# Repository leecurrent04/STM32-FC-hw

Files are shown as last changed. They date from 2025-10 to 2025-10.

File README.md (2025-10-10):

# NARAEON (나래온)

**NARAEON**은 인하대학교 모형항공기 동아리 '나래'(NARAE)에서 개발 중인 오픈소스 비행제어컴퓨터(FC) 프로젝트입니다. 이 프로젝트는 학술적 연구, 개발 그리고 취미 활동을 목적으로 하는 모든 분들을 위해 하드웨어, 펌웨어를 포함하고 있습니다.

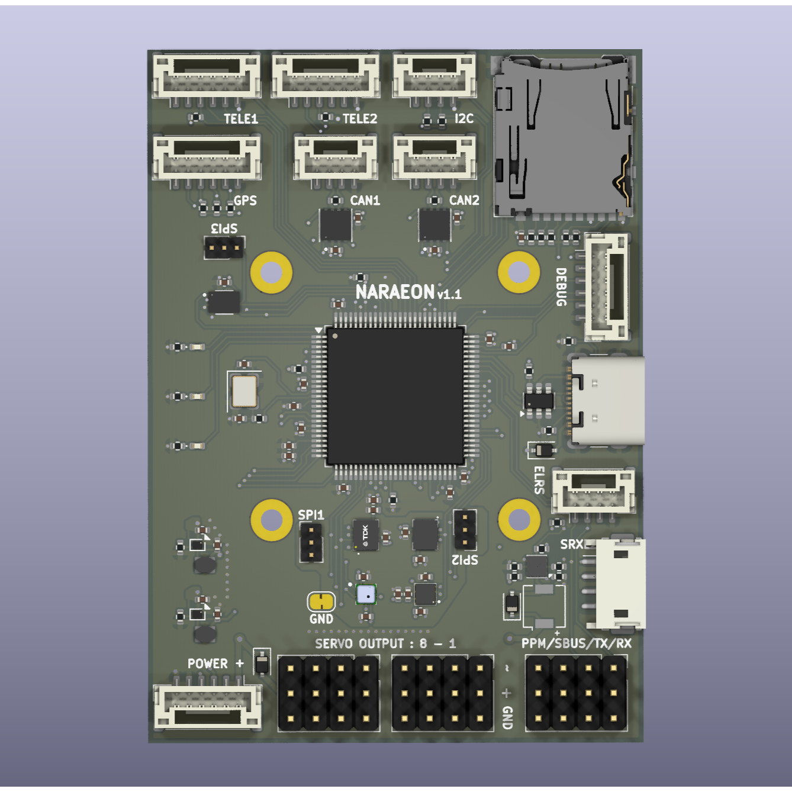
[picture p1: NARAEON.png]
pcb img


## 🌟 프로젝트 소개
NARAEON은 무인항공기(UAV)의 핵심인 **비행제어컴퓨터**와 주요 센서들을 아우르는 통합 플랫폼입니다. 
저희는 항공전자 분야를 처음 배우는 학생들이 쉽게 학습하고 새로운 기능을 구현 및 창조할 수 있는 플랫폼을 제공하고자 이 프로젝트를 시작하게 되었습니다.

## ✨ 주요 특징
- 오픈소스: 하드웨어 회로도부터 펌웨어 소스 코드까지 모든 것이 공개되어 있어 누구나 자유롭게 사용하고, 수정하며, 기여할 수 있습니다.
- 통합 플랫폼: 비행 제어에 필요한 컴퓨터와 핵심 센서를 포함하여 안정적인 비행 제어 솔루션을 제공합니다.
- 확장성: 다양한 종류의 무인항공기에 적용할 수 있도록 설계되었으며, 사용자의 필요에 따라 기능을 쉽게 확장할 수 있습니다.
- 교육 및 연구: 학생, 연구자, 개발자들이 비행 제어 시스템의 원리를 깊이 있게 학습하고, 새로운 기술을 실험할 수 있는 훌륭한 교육 및 연구 도구입니다.

## 🚀 시작하기
프로젝트를 시작하는 데 필요한 정보는 각 저장소의 Wiki 페이지나 문서를 참고해 주세요. (링크 추가 예정)

하드웨어: [하드웨어 관련 저장소 링크]

- [STM32-FC](https://github.com/NARAE-INHA-UNIV/STM32-FC) : Firmware & Source code
- [NALDA](https://github.com/NARAE-INHA-UNIV/NALDA) : GCS

## 🔍 HW Spec.

> PCB 보드에 릴리즈 날짜와 버전이 기록되어 있지 않으면 v1.0.0 버전 입니다.
현재 최신 버전은 v1.1.0 입니다.

- ICM-45686 & ICM-42688-P dual IMU
- LIS2MDL eCompass
- ICP-20100 pressure sensor
- 내장 Flash memory & Micro SD card
- IBUS, SBUS, SRXL2, ELRS, PPM RC 프로토콜 지원

## 🤝 기여하기

NARAEON 프로젝트는 여러분의 참여를 언제나 환영합니다! 버그 리포트, 기능 제안, 코드 기여 등 어떤 형태의 기여도 프로젝트 발전에 큰 힘이 됩니다. 기여하고 싶으시다면 다음을 참고해 주세요.

1. 이 저장소를 Fork 하세요.
2. 새로운 기능이나 수정을 위한 Branch를 생성하세요 (git checkout -b feature/AmazingFeature).
3. 코드를 수정하고 Commit 하세요 (git commit -m 'Add some AmazingFeature').
4. Branch에 Push 하세요 (git push origin feature/AmazingFeature).
5. Pull Request를 열어주세요.

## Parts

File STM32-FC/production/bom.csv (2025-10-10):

Designator | Footprint | Quantity | Value | LCSC Part #
BZ1 | FUET-4020 | 1 | FUET-4020 | C391027
C1, C4 | 0402 | 2 | 10pF | C1545
C10, C11, C13, C18, C19, C22, C24, C25, C27, C28, C3, C30, C31, C32, C33, C34, C5, C6, C9 | 0402 | 19 | 100nF | C1525
C12 | 0402 | 1 | 1uF | C14445
C14, C15 | 0402 | 2 | 4.7uF | C307423
C16, C17, C2, C26 | 0402 | 4 | 10uF | C307415
C20 | 0402 | 1 | 10nF | C15195
C21 | 0402 | 1 | 100pF | C152819
C23 | 0402 | 1 | 2.2nF | C84703
C29 | 0402 | 1 | 220nF | C16651
C7, C8 | 0402 | 2 | 2.2uF | C170151
D1 | 0402 | 1 | Red | C130719
D2, D5, D6 | D_SOD-323 | 3 | B5819W | C22624
D3 | 0402 | 1 | Yellow | C130721
D4 | 0402 | 1 | Blue | C130724
J1, J10, J11, J15, J3 | JST_GH_BM06B-GHS-TBT_1x06-1MP_P1.25mm_Vertical | 5 | GH 1.25mm 6P | C189892
J12, J13, J14, J9 | JST_GH_BM04B-GHS-TBT_1x04-1MP_P1.25mm_Vertical | 4 | GH 1.25mm 4P | C161692
J2 | USB_C_Receptacle_GCT_USB4105-xx-A_16P_TopMnt_Horizontal | 1 | USB_C_USB2.0_16P | C2765186
J4 | microSD_HC_Hirose_DM3AT-SF-PEJM5 | 1 | DM3AT-SF-PEJM5 | C114218
J5, J6, J7 | PWM_Conn_3x04_JLC | 3 | PWM_Conn_3x04 | C3325573
J8 | JST_ZH_B4B-ZR-SM4-TF_1x04-1MP_P1.50mm_Vertical | 1 | ZH 1.5mm 4P | C485354
L1, L2 | VLS201610ET-2R2M | 2 | 2.2u | C114768
Q1 | Nexperia_SOT1118 | 1 | PMDPB30XN | C478009
R1, R3 | 0402 | 2 | 100k | C25741
R10 | 0402 | 1 | 1k5 | C25867
R11, R12 | 0402 | 2 | 267k | C2998050
R13, R14, R15, R16, R17, R18, R19, R21, R22, R23, R24, R25, R28, R29, R30, R31, R34 | 0402 | 17 | 10k | C25531
R2 | 0402 | 1 | 4k7 | C25900
R26, R27, R33, R4 | 0402 | 4 | 120 | C25079
R5, R6, R7 | 0402 | 3 | 1k | C11702
R8, R9 | 0402 | 2 | 5k1 | C25905
TP1, TP2, TP3 | PinHeader_1x03_P1.27mm_Vertical | 3 | Test Pin | C24980
U1 | LQFP-100_14x14mm_P0.5mm | 1 | STM32F407VETx | C28730
U10, U11 | VDFN8_3X3_MCH-L | 2 | ATA6561-GBQW | C617297
U2 | SOT-23-6 | 1 | USBLC6-2SC6 | C7519
U3, U4 | Texas_DSBGA-6_0.855x1.255mm_Layout2x3_P0.4mm_LevelC | 2 | TPS62840YBG | C2071139
U5 | USON_LUXIG TR_WIN | 1 | W25X40CLUXIG | C401661
U6 | IIM42352_L | 1 | ICM-42688-P | C1850418
U7 | ICM-45686 | 1 | ICM-45686 | C22459454
U8 | ICP-20100 | 1 | ICP-20100 | C5343527
U9 | LIS2MDLTR | 1 | LIS2MDLRT | C919695
Y1 | Crystal_SMD_Abracon_ABM8G-4Pin_3.2x2.5mm | 1 | 16MHz | C1985423

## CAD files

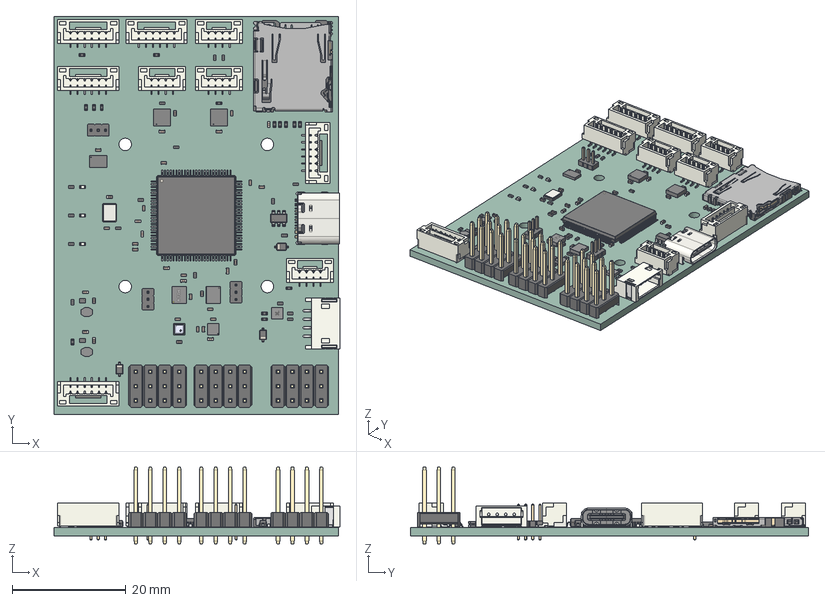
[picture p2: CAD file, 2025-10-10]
NARAEON.step
50.2 x 70.0 x 13.5 mm
LED_0402_1005Metric x 3
LIS2MDLTR
kicad_embedded_6C539A5BD06C60DE5F29B901A99F0E48
R_0402_1005Metric x 32
C_0402_1005Metric x 34
JST_GH_BM04B-GHS-TBT_1x04-1MP_P1.25mm_Vertical x 4
JST_GH_BM06B-GHS-TBT_1x06-1MP_P1.25mm_Vertical x 5
PinHeader_1x03_P1.27mm_Vertical x 3
kicad_embedded_F2643CE658DD47BC4DB3F655A425A60D
3x4 Male Pin Header x 3
Crystal_SMD_Abracon_ABM8G-4Pin_3.2x2.5mm
ICP-20100
SOT1118 LF
SOT1118 Mold Body
S4B-ZR-SM4A-TF
VDFN8_3X3_MCH x 2
D_SOD-323 x 3
USON_LUXIG_TR_WIN
SOT-23-6
USB_C_Receptacle_GCT_USB4105-xx-A_16P_TopMnt_Horizontal
ICM-42688-P
Texas_DSBGA-6_0.757x1.01mm_Layout2x3_P0.35mm x 2
LQFP-100_14x14mm_P0.5mm
kicad_embedded_0F5F1D1E837527C3A2AA1D8B906FDBF7 x 2
microSD_HC_Hirose_DM3AT-SF-PEJM5
STM32-FC_PCB

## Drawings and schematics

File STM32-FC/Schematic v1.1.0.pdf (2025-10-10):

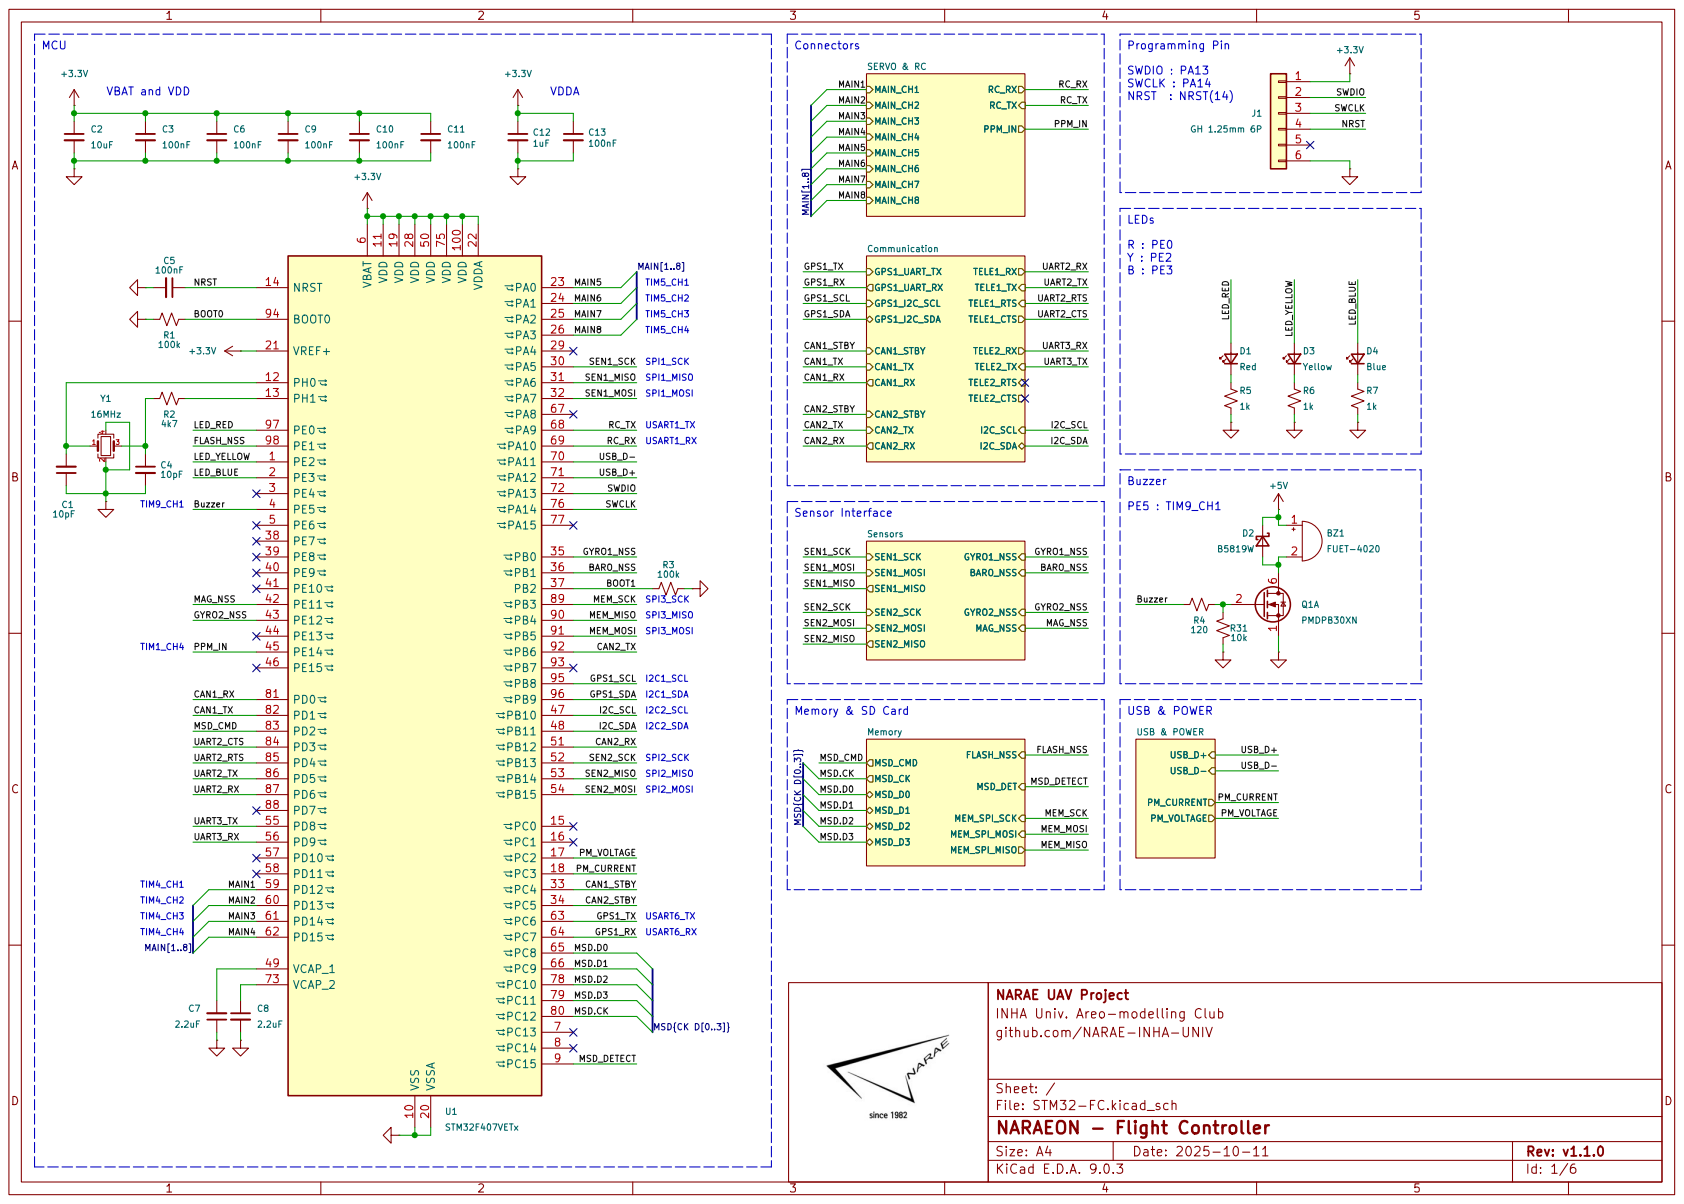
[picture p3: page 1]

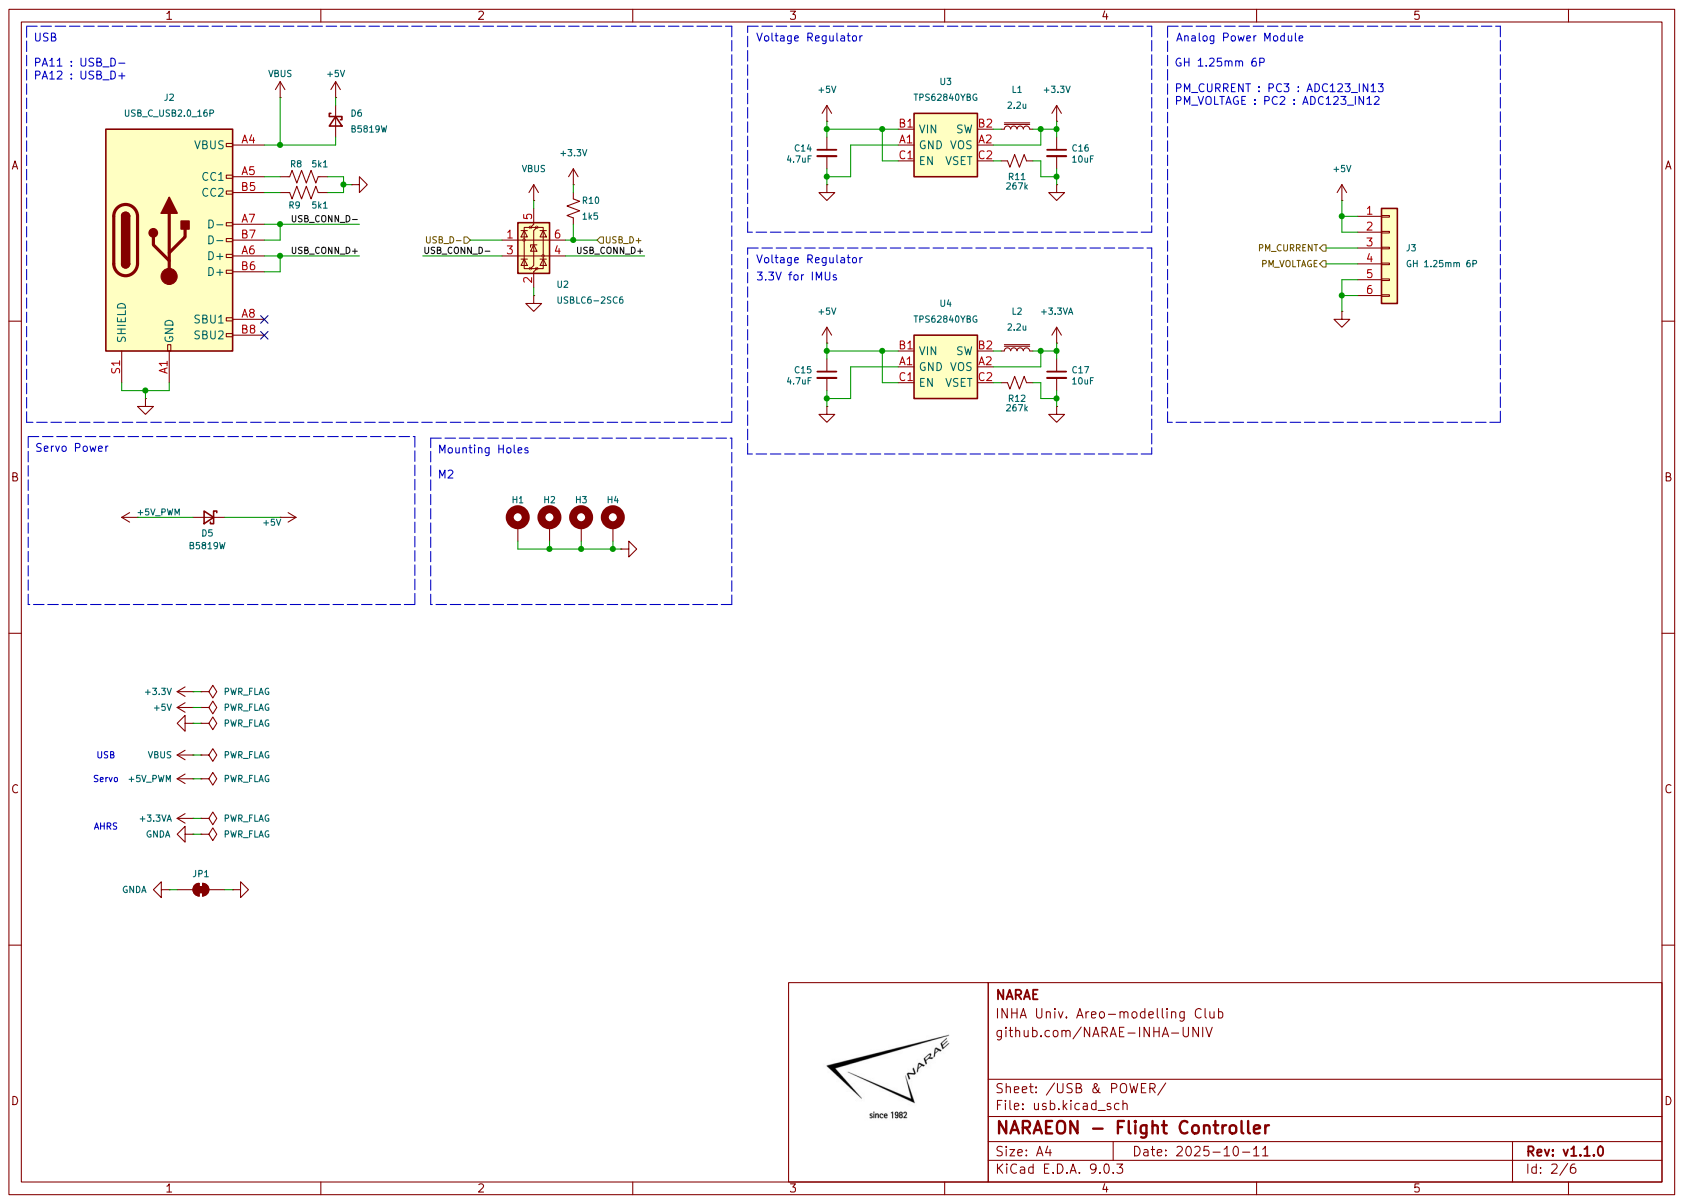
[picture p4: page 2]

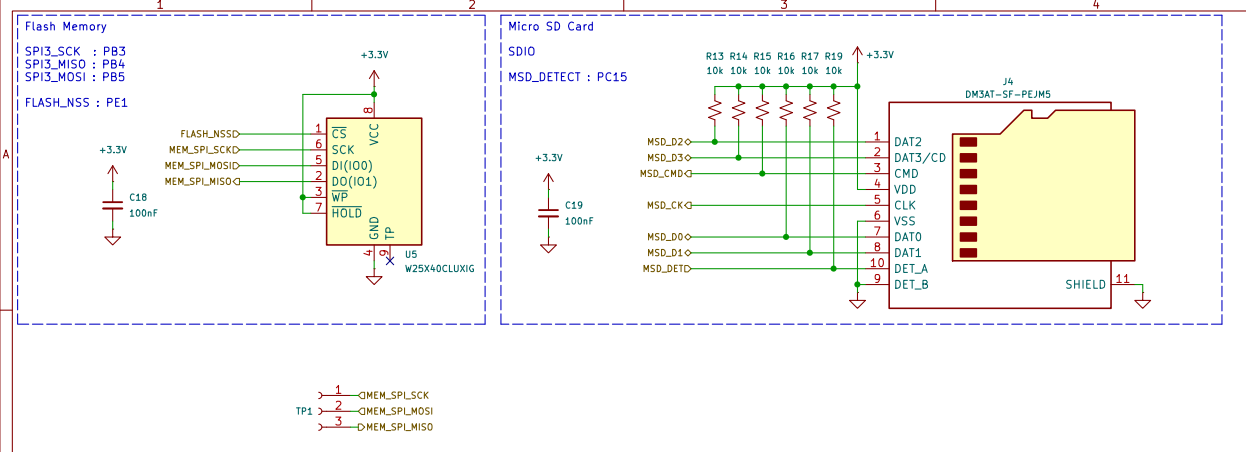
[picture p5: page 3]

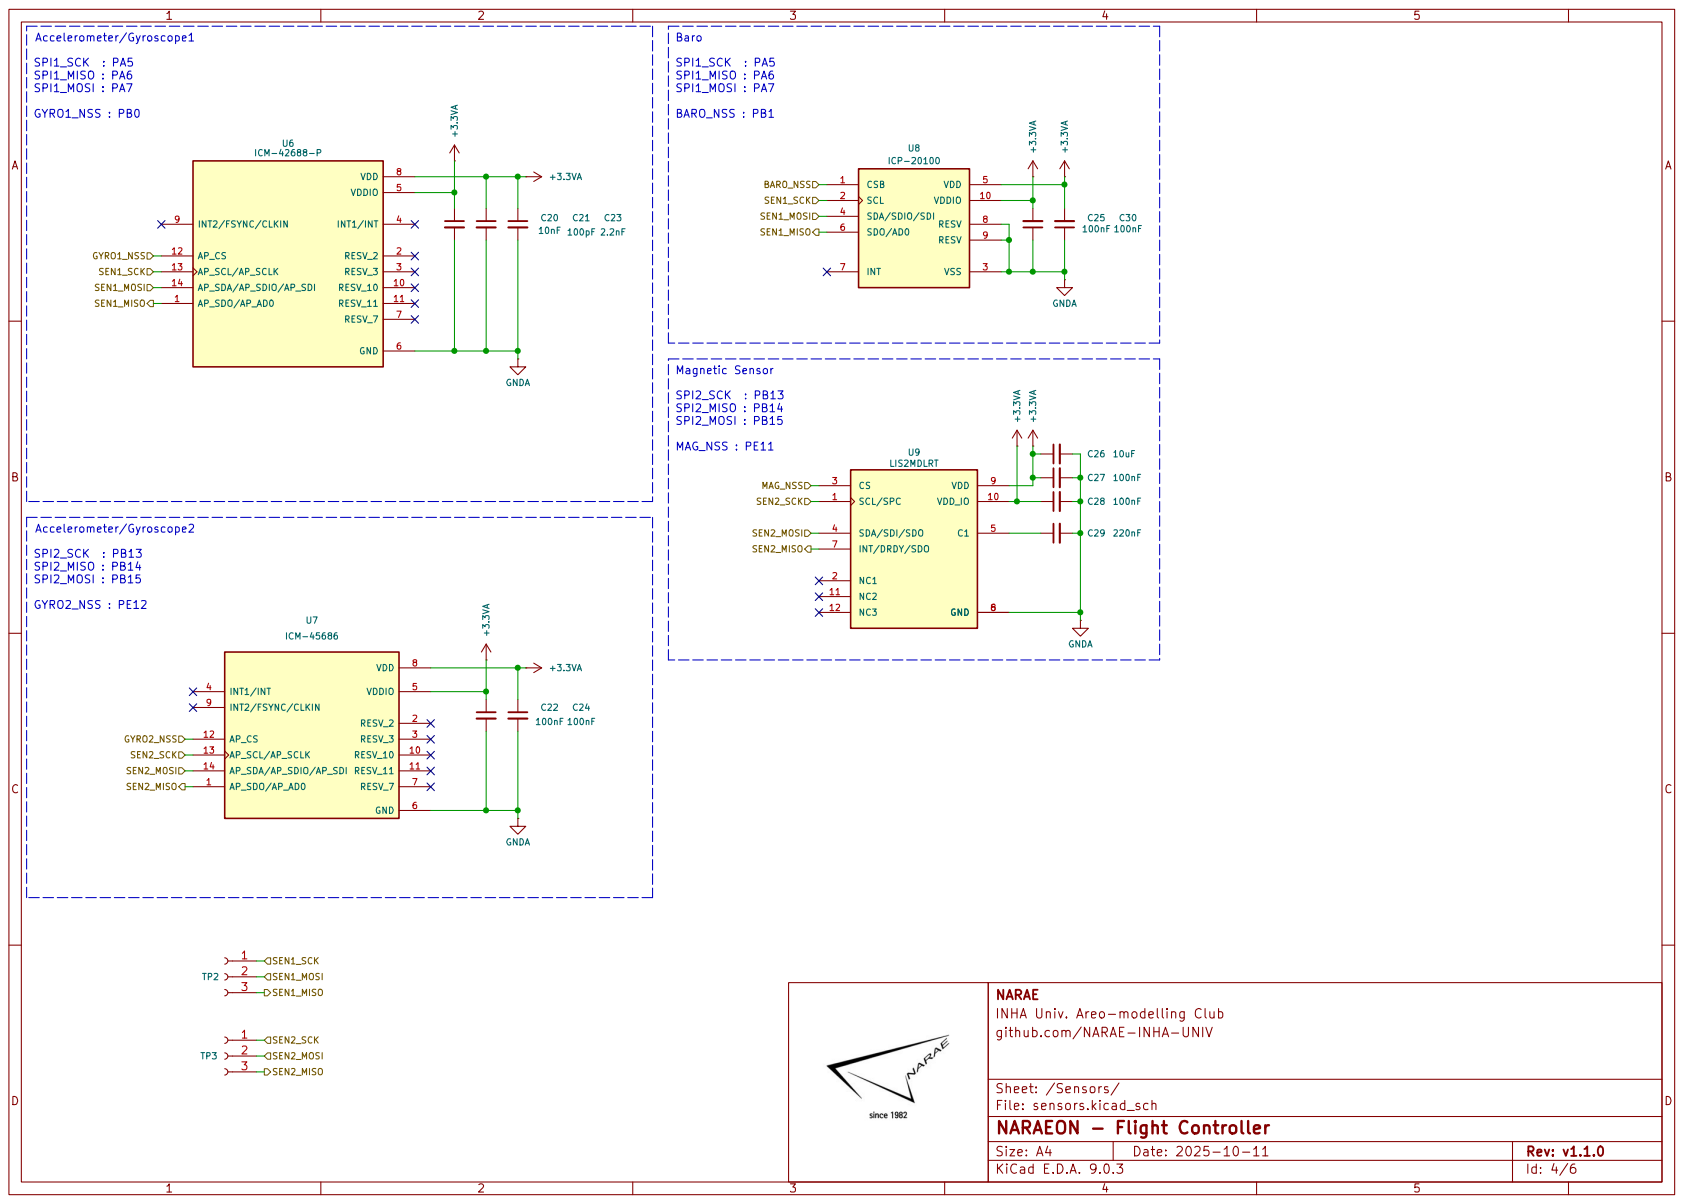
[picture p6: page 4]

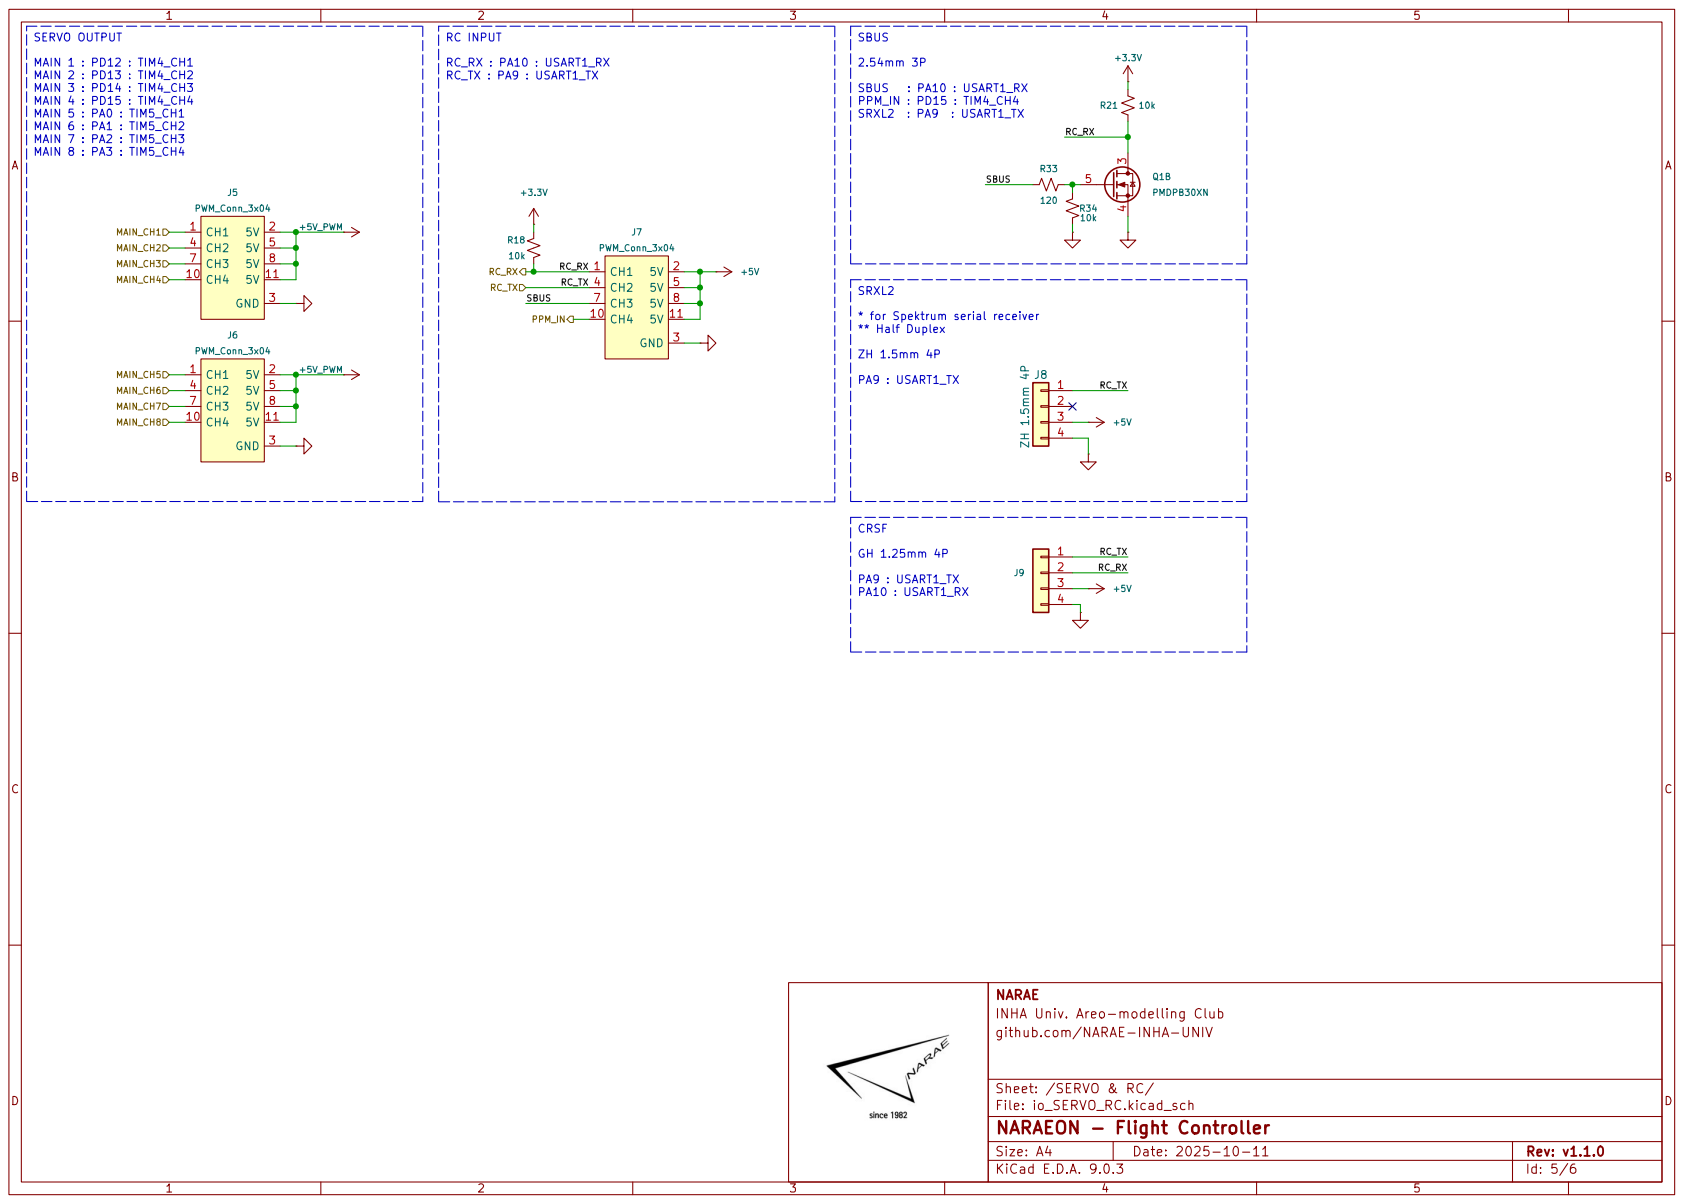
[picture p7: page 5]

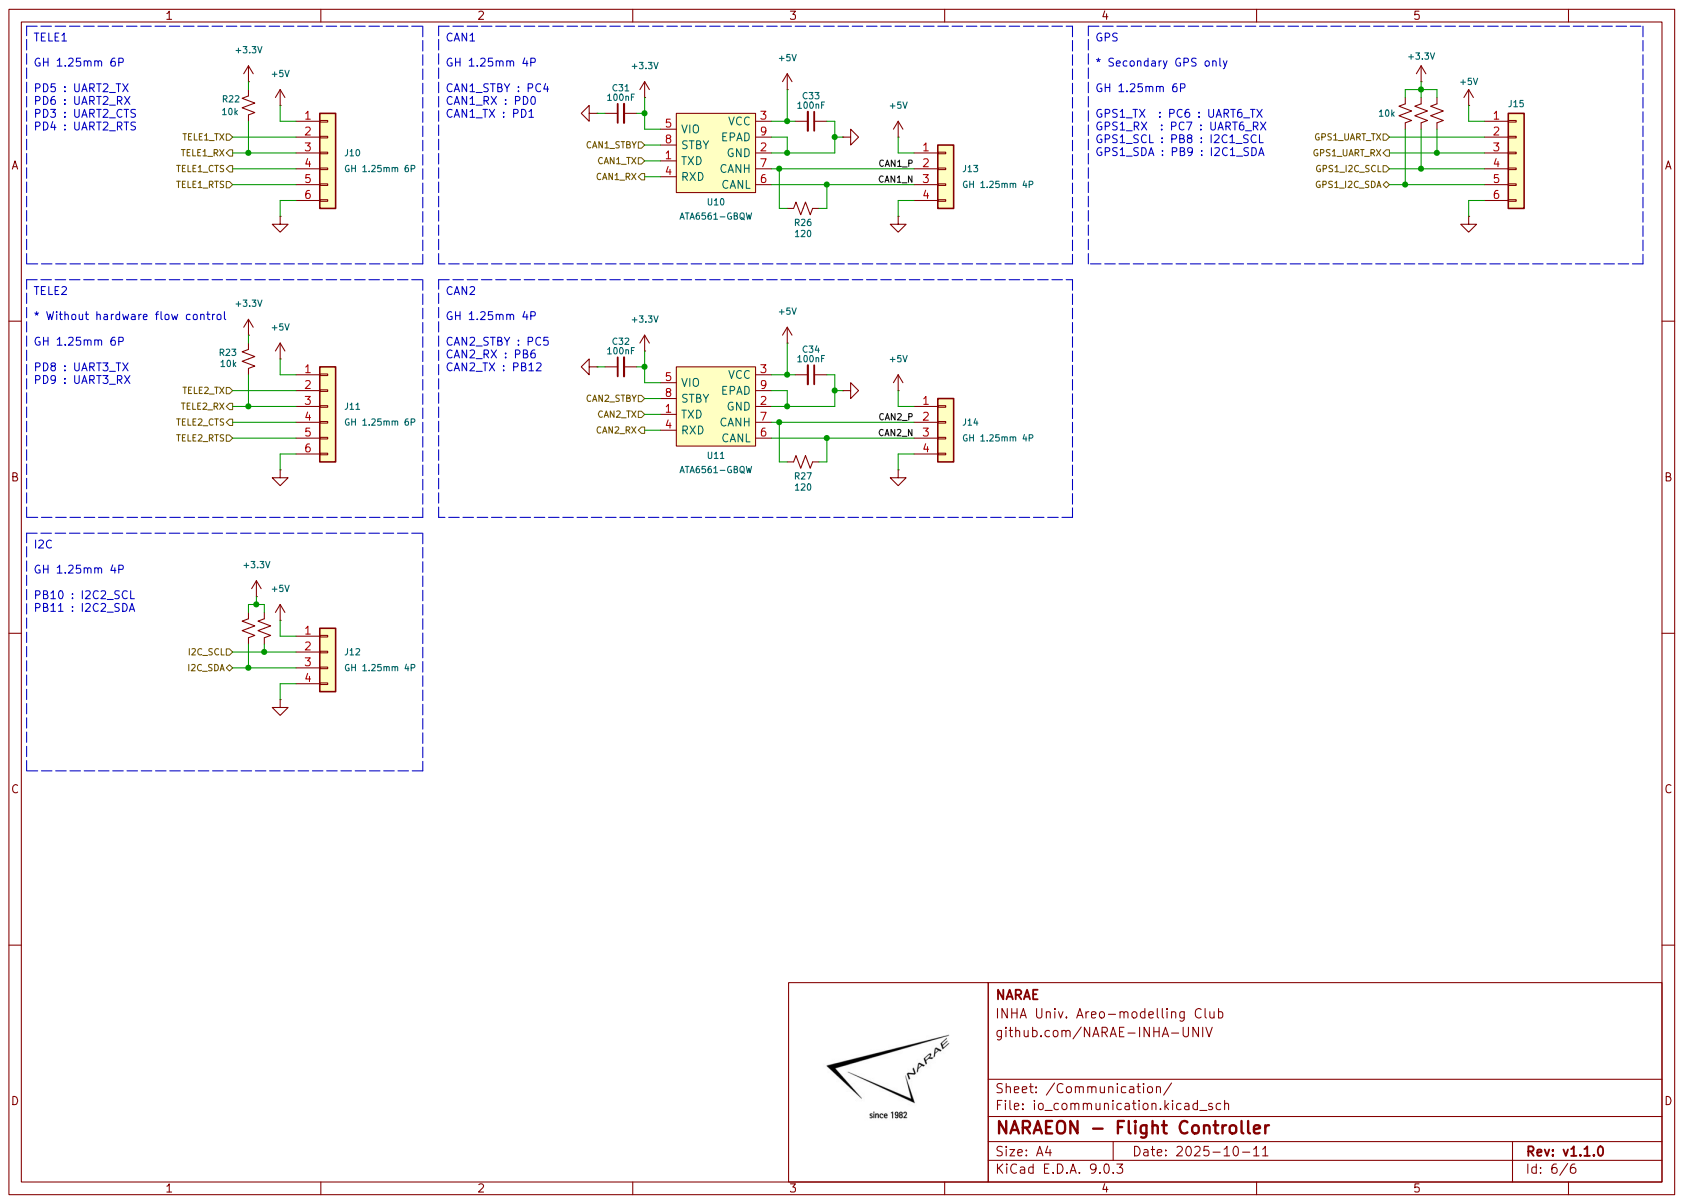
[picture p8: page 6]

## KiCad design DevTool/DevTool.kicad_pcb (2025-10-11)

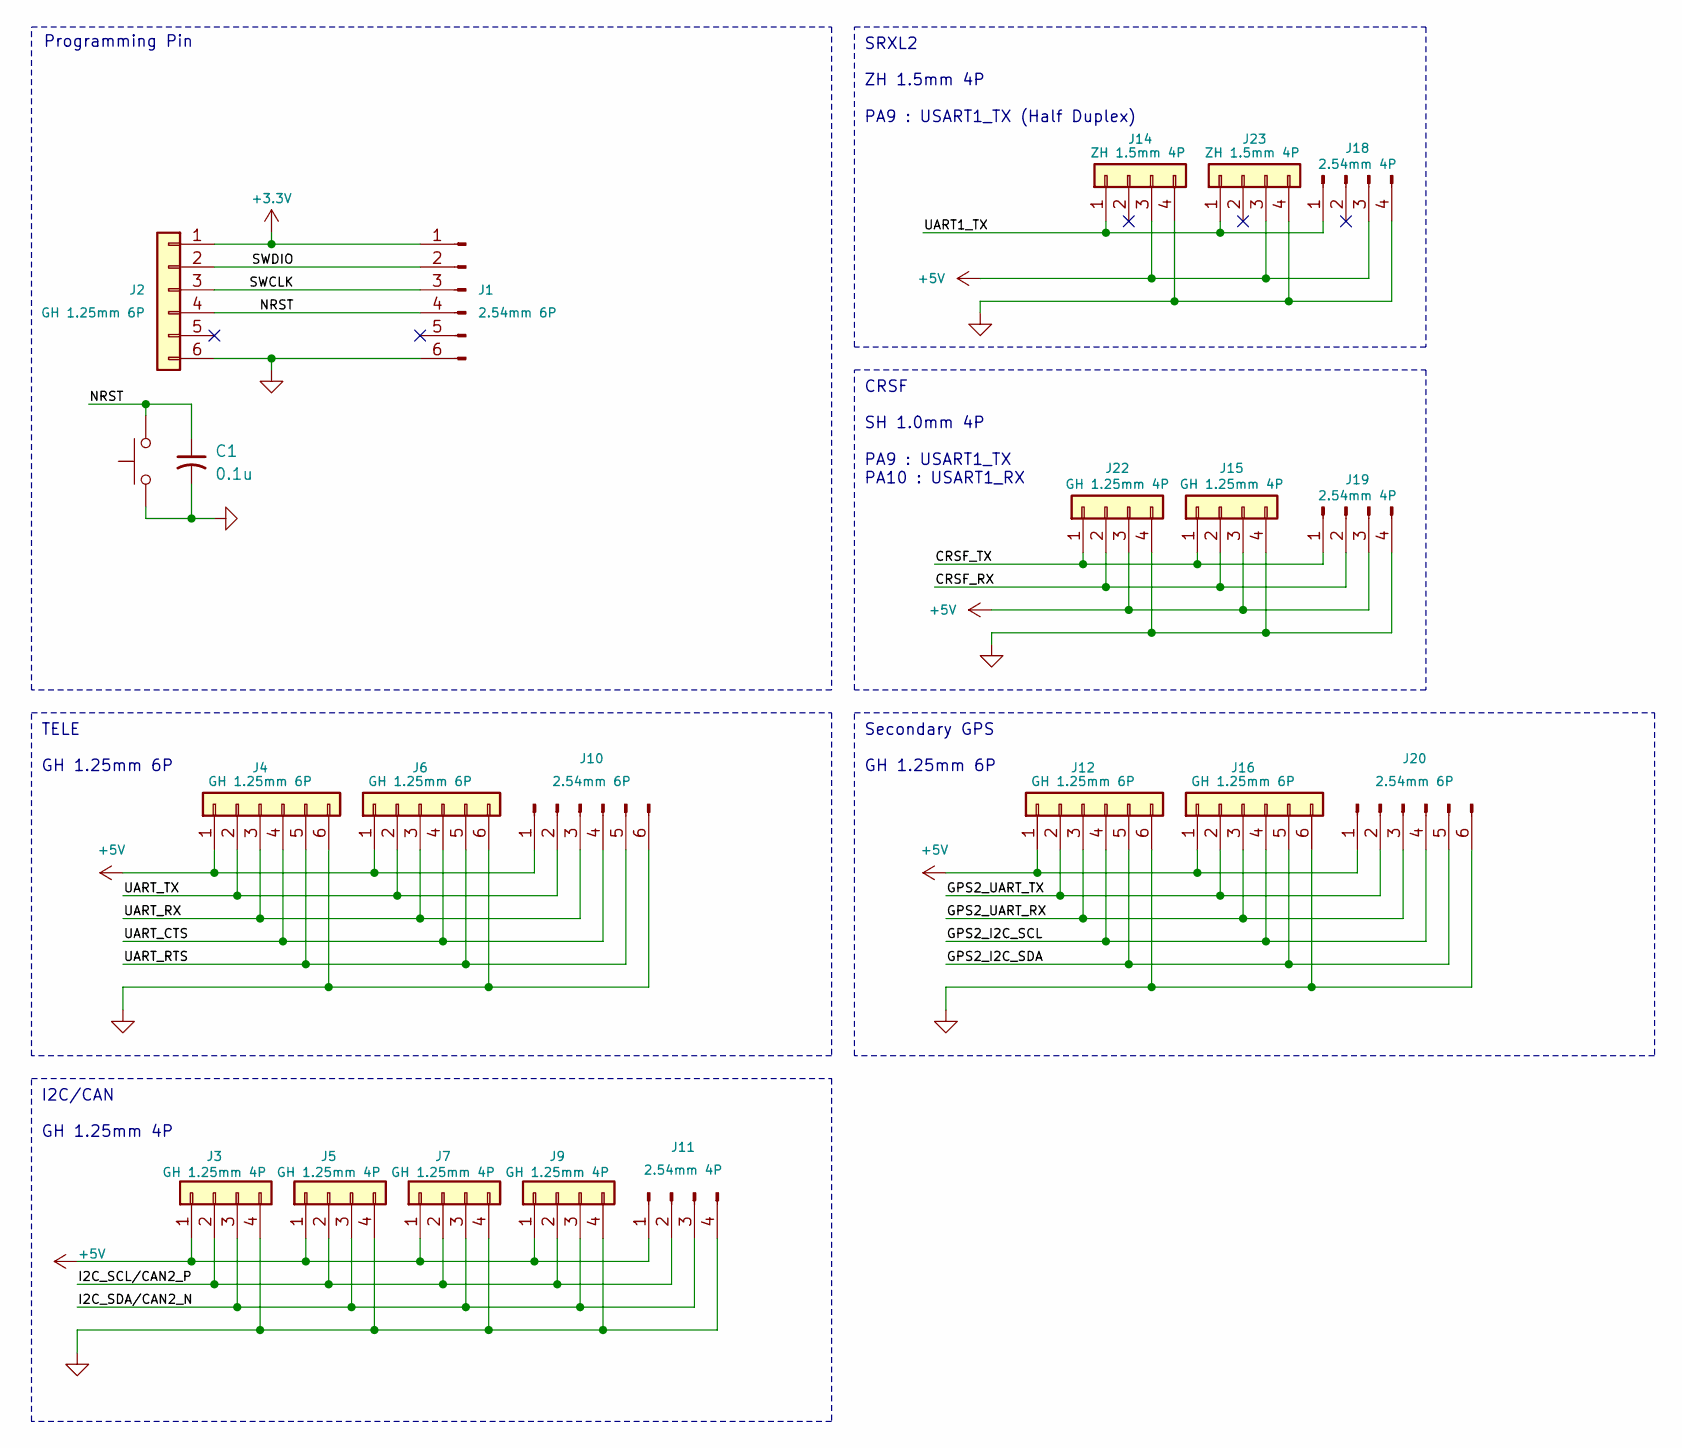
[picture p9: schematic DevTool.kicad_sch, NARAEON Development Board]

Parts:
C1: 0.1u; C_0603_1608Metric
J1, J10, J20: 2.54mm 6P; PinHeader_1x06_P2.54mm_Vertical
J2, J4, J6, J12, J16: GH 1.25mm 6P; JST_GH_BM06B-GHS-TBT_06; LCSC C133065
J3, J5, J7, J9, J15, J22: GH 1.25mm 4P; JST_GH_BM04B-GHS-TBT_04; LCSC C189895
J11, J18, J19: 2.54mm 4P; PinHeader_1x04_P2.54mm_Vertical
J14, J23: ZH 1.5mm 4P; JST_ZH_S4B-ZR-SM4A-TF_1x04-1MP_P1.50mm_Horizontal; LCSC C485354
SW1: SW_Push; SW_SPST_PTS645

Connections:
+3.3V: J1.1, J2.1
+5V: J3.1, J4.1, J5.1, J6.1, J7.1, J9.1, J10.1, J11.1, J12.1, J14.3, J15.3, J16.1, J18.3, J19.3, J20.1, J22.3, J23.3
/CRSF_RX: J15.2, J19.2, J22.2
/CRSF_TX: J15.1, J19.1, J22.1
/GPS2_I2C_SCL: J12.4, J16.4, J20.4
/GPS2_I2C_SDA: J12.5, J16.5, J20.5
/GPS2_UART_RX: J12.3, J16.3, J20.3
/GPS2_UART_TX: J12.2, J16.2, J20.2
/I2C_SCL/CAN2_P: J3.2, J5.2, J7.2, J9.2, J11.2
/I2C_SDA/CAN2_N: J3.3, J5.3, J7.3, J9.3, J11.3
/NRST: C1.1, J1.4, J2.4, SW1.2
/SWCLK: J1.3, J2.3
/SWDIO: J1.2, J2.2
/UART1_TX: J14.1, J18.1, J23.1
/UART_CTS: J4.4, J6.4, J10.4
/UART_RTS: J4.5, J6.5, J10.5
/UART_RX: J4.3, J6.3, J10.3
/UART_TX: J4.2, J6.2, J10.2
GND: C1.2, J1.6, J2.6, J3.4, J4.6, J5.4, J6.6, J7.4, J9.4, J10.6, J11.4, J12.6, J14.4, J15.4, J16.6, J18.4, J19.4, J20.6, J22.4, J23.4, SW1.1

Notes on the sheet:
SRXL2
CRSF
SH 1.0mm 4P PA9 : USART1_TX PA10 : USART1_RX
GH 1.25mm 6P
Programming Pin
TELE
GH 1.25mm 4P
I2C/CAN
Secondary GPS
ZH 1.5mm 4P PA9 : USART1_TX (Half Duplex)

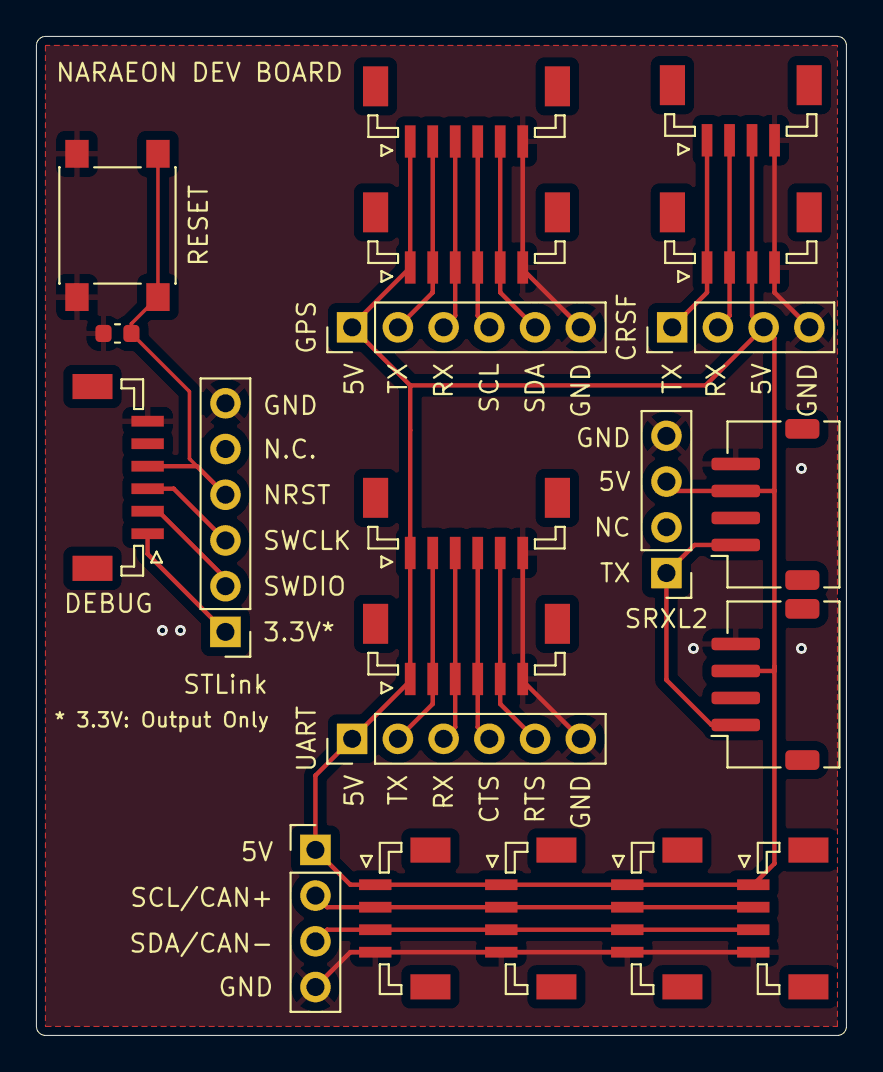
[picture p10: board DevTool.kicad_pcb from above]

Board: 2 copper layers, 45.0 x 55.5 mm, 21 parts (0 on the bottom side), 19 nets.

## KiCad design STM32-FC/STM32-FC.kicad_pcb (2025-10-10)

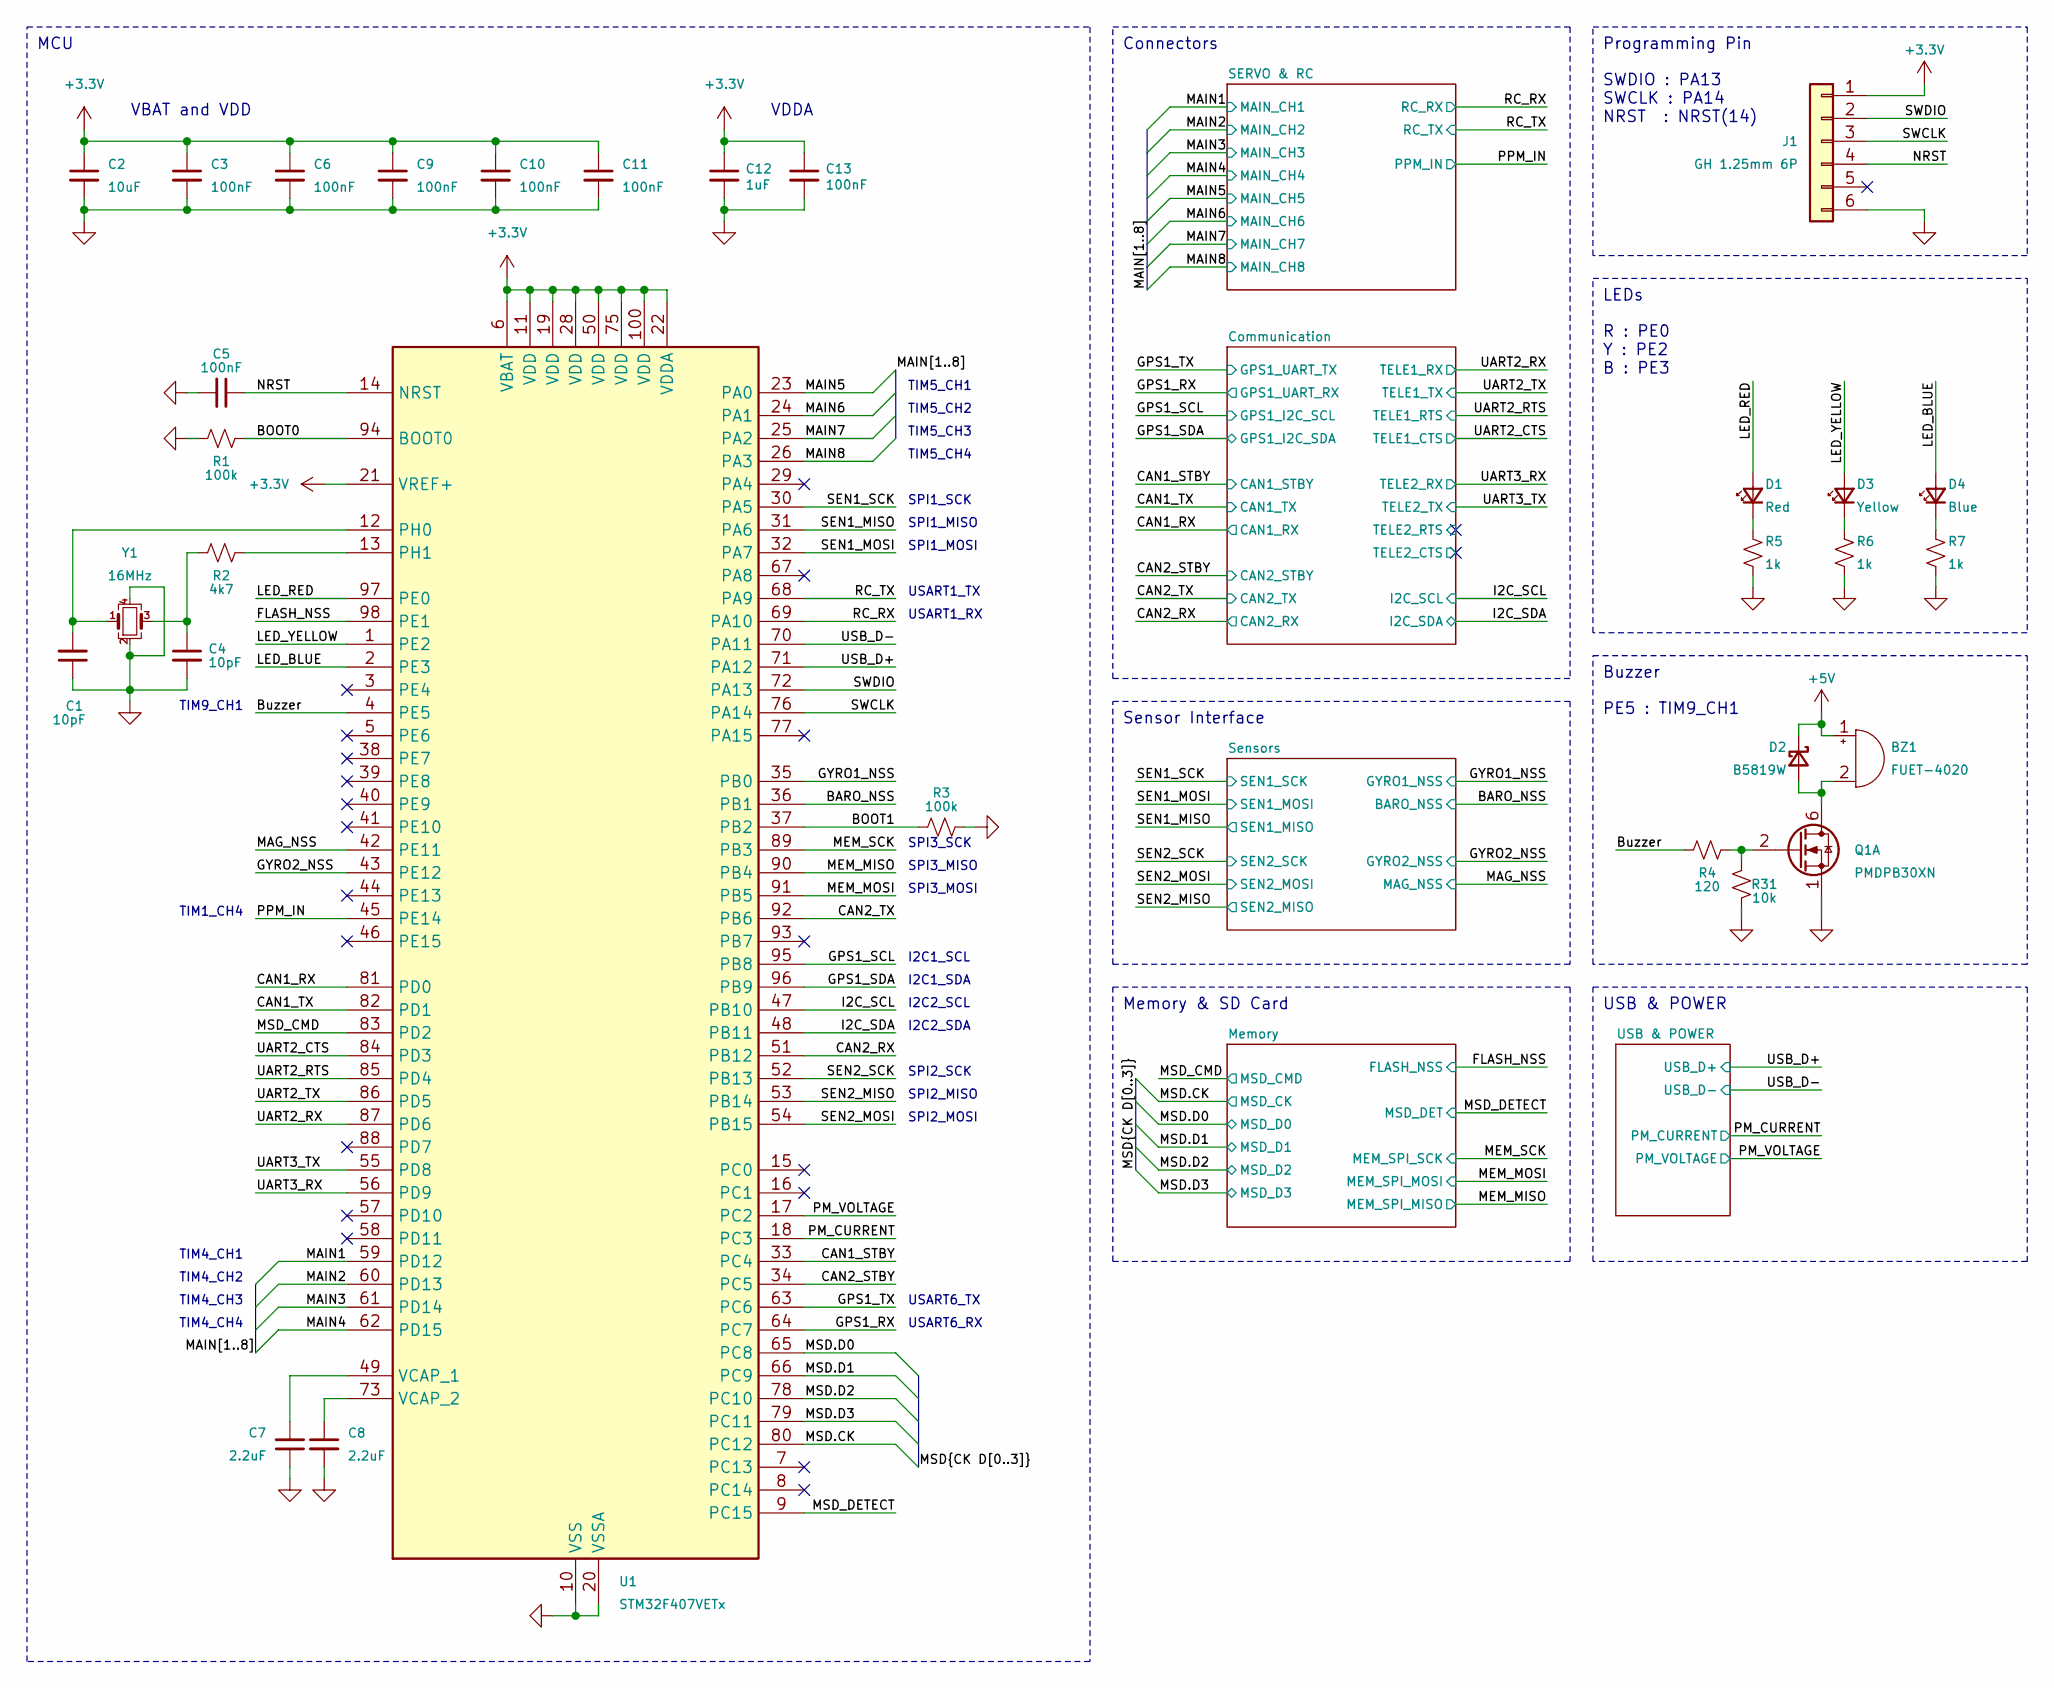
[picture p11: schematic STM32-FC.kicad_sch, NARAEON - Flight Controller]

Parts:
BZ1: FUET-4020; LCSC C391027
C1, C4: 10pF; C_0402_1005Metric; LCSC C1545
C2: 10uF; C_0402_1005Metric; LCSC C307415
C3, C5, C6, C9, C10, C11, C13: 100nF; C_0402_1005Metric; LCSC C1525
C7, C8: 2.2uF; C_0402_1005Metric; LCSC C170151
C12: 1uF; C_0402_1005Metric; LCSC C14445
D1: Red; LED_0402_1005Metric; LCSC C130719
D2: B5819W; D_SOD-323; LCSC C22624
D3: Yellow; LED_0402_1005Metric; LCSC C130721
D4: Blue; LED_0402_1005Metric; LCSC C130724
J1: GH 1.25mm 6P; JST_GH_BM06B-GHS-TBT_1x06-1MP_P1.25mm_Vertical; LCSC C189892
Q1: PMDPB30XN; Nexperia_SOT1118; LCSC C478009
R1, R3: 100k; R_0402_1005Metric; LCSC C25741
R2: 4k7; R_0402_1005Metric; LCSC C25900
R4: 120; R_0402_1005Metric; LCSC C25079
R5, R6, R7: 1k; R_0402_1005Metric; LCSC C11702
R31: 10k; R_0402_1005Metric; LCSC C25531
U1: STM32F407VETx; LQFP-100_14x14mm_P0.5mm; LCSC C28730
Y1: 16MHz; Crystal_SMD_Abracon_ABM8G-4Pin_3.2x2.5mm; LCSC C1985423

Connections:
+3.3V: C2.1, C3.1, C6.1, C9.1, C10.1, C11.1, C12.1, C13.1, J1.1, U1.6 (VBAT), U1.11 (VDD), U1.19 (VDD), U1.21 (VREF+), U1.22 (VDDA), U1.28 (VDD), U1.50 (VDD), U1.75 (VDD), U1.100 (VDD); also elsewhere on the board
+5V: BZ1.1 (-), D2.1 (K); also elsewhere on the board
/BARO_NSS: U1.36 (PB1); also elsewhere on the board
/BOOT0: R1.2, U1.94 (BOOT0)
/BOOT1: R3.2, U1.37 (PB2)
/Buzzer: R4.1, U1.4 (PE5)
/CAN1_RX: U1.81 (PD0); also elsewhere on the board
/CAN1_STBY: U1.33 (PC4); also elsewhere on the board
/CAN1_TX: U1.82 (PD1); also elsewhere on the board
/CAN2_RX: U1.51 (PB12); also elsewhere on the board
/CAN2_STBY: U1.34 (PC5); also elsewhere on the board
/CAN2_TX: U1.92 (PB6); also elsewhere on the board
/FLASH_NSS: U1.98 (PE1); also elsewhere on the board
/GPS1_RX: U1.64 (PC7); also elsewhere on the board
/GPS1_SCL: U1.95 (PB8); also elsewhere on the board
/GPS1_SDA: U1.96 (PB9); also elsewhere on the board
/GPS1_TX: U1.63 (PC6); also elsewhere on the board
/GYRO1_NSS: U1.35 (PB0); also elsewhere on the board
/GYRO2_NSS: U1.43 (PE12); also elsewhere on the board
/I2C1_SCL: U1.47 (PB10); also elsewhere on the board
/I2C1_SDA: U1.48 (PB11); also elsewhere on the board
/LED_BLUE: D4.2 (A), U1.2 (PE3)
/LED_RED: D1.2 (A), U1.97 (PE0)
/LED_YELLOW: D3.2 (A), U1.1 (PE2)
/MAG_NSS: U1.42 (PE11); also elsewhere on the board
/MAIN1: U1.59 (PD12); also elsewhere on the board
/MAIN2: U1.60 (PD13); also elsewhere on the board
/MAIN3: U1.61 (PD14); also elsewhere on the board
/MAIN4: U1.62 (PD15); also elsewhere on the board
/MAIN5: U1.23 (PA0); also elsewhere on the board
/MAIN6: U1.24 (PA1); also elsewhere on the board
/MAIN7: U1.25 (PA2); also elsewhere on the board
/MAIN8: U1.26 (PA3); also elsewhere on the board
/MEM_MISO: U1.90 (PB4); also elsewhere on the board
/MEM_MOSI: U1.91 (PB5); also elsewhere on the board
/MEM_SCK: U1.89 (PB3); also elsewhere on the board
/MSD.CK: U1.80 (PC12); also elsewhere on the board
/MSD.D0: U1.65 (PC8); also elsewhere on the board
/MSD.D1: U1.66 (PC9); also elsewhere on the board
/MSD.D2: U1.78 (PC10); also elsewhere on the board
/MSD.D3: U1.79 (PC11); also elsewhere on the board
/MSD_CMD: U1.83 (PD2); also elsewhere on the board
/MSD_DETECT: U1.9 (PC15); also elsewhere on the board
/NRST: C5.1, J1.4, U1.14 (NRST)
/PM_CURRENT: U1.18 (PC3); also elsewhere on the board
/PM_VOLTAGE: U1.17 (PC2); also elsewhere on the board
/PPM_IN: U1.45 (PE14); also elsewhere on the board
/RC_RX: U1.69 (PA10); also elsewhere on the board
/RC_TX: U1.68 (PA9); also elsewhere on the board
/SEN1_MISO: U1.31 (PA6); also elsewhere on the board
/SEN1_MOSI: U1.32 (PA7); also elsewhere on the board
/SEN1_SCK: U1.30 (PA5); also elsewhere on the board
/SEN2_MISO: U1.53 (PB14); also elsewhere on the board
/SEN2_MOSI: U1.54 (PB15); also elsewhere on the board
/SEN2_SCK: U1.52 (PB13); also elsewhere on the board
/SWCLK: J1.3, U1.76 (PA14)
/SWDIO: J1.2, U1.72 (PA13)
/UART2_CTS: U1.84 (PD3); also elsewhere on the board
/UART2_RTS: U1.85 (PD4); also elsewhere on the board
/UART2_RX: U1.87 (PD6); also elsewhere on the board
/UART2_TX: U1.86 (PD5); also elsewhere on the board
/UART3_RX: U1.56 (PD9); also elsewhere on the board
/UART3_TX: U1.55 (PD8); also elsewhere on the board
/USB_D+: U1.71 (PA12); also elsewhere on the board
/USB_D-: U1.70 (PA11); also elsewhere on the board
GND: C1.1, C2.2, C3.2, C4.2, C5.2, C6.2, C7.1, C8.2, C9.2, C10.2, C11.2, C12.2, C13.2, J1.6, Q1.1 (S), R1.1, R3.1, R5.2, R6.2, R7.2, R31.2, U1.10 (VSS), U1.20 (VSSA), U1.27 (VSS), U1.74 (VSS), U1.99 (VSS), Y1.2, Y1.4; also elsewhere on the board
unnamed: BZ1.2 (+), D2.2 (A), Q1.6 (D), Q1.7 (D)
unnamed: C4.1, R2.1, Y1.3
unnamed: D1.1 (K), R5.1
unnamed: D3.1 (K), R6.1
unnamed: D4.1 (K), R7.1
unnamed: Q1.2 (G), R4.2, R31.1
unnamed: C1.2, U1.12 (PH0), Y1.1
unnamed: R2.2, U1.13 (PH1)
unnamed: C7.2, U1.49 (VCAP_1)
unnamed: C8.1, U1.73 (VCAP_2)

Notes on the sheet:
Connectors
PE5 : TIM9_CH1
TIM9_CH1
TIM5_CH1
TIM4_CH3
SPI3_SCK
SPI3_MISO
TIM4_CH1
I2C2_SCL
USART6_RX
TIM4_CH2
MCU
VDDA
USART1_TX
SPI2_MOSI
SPI3_MOSI
Buzzer
TIM1_CH4
I2C1_SCL
USART1_RX
TIM5_CH3
Sensor Interface
LEDs
Programming Pin
TIM5_CH4
Memory & SD Card
USB & POWER
SPI1_MOSI
I2C1_SDA
USART6_TX
R : PE0 Y : PE2 B : PE3
TIM4_CH4
TIM5_CH2
SPI2_SCK
SWDIO : PA13 SWCLK : PA14 NRST : NRST(14)
SPI1_MISO
I2C2_SDA
VBAT and VDD
SPI2_MISO
SPI1_SCK

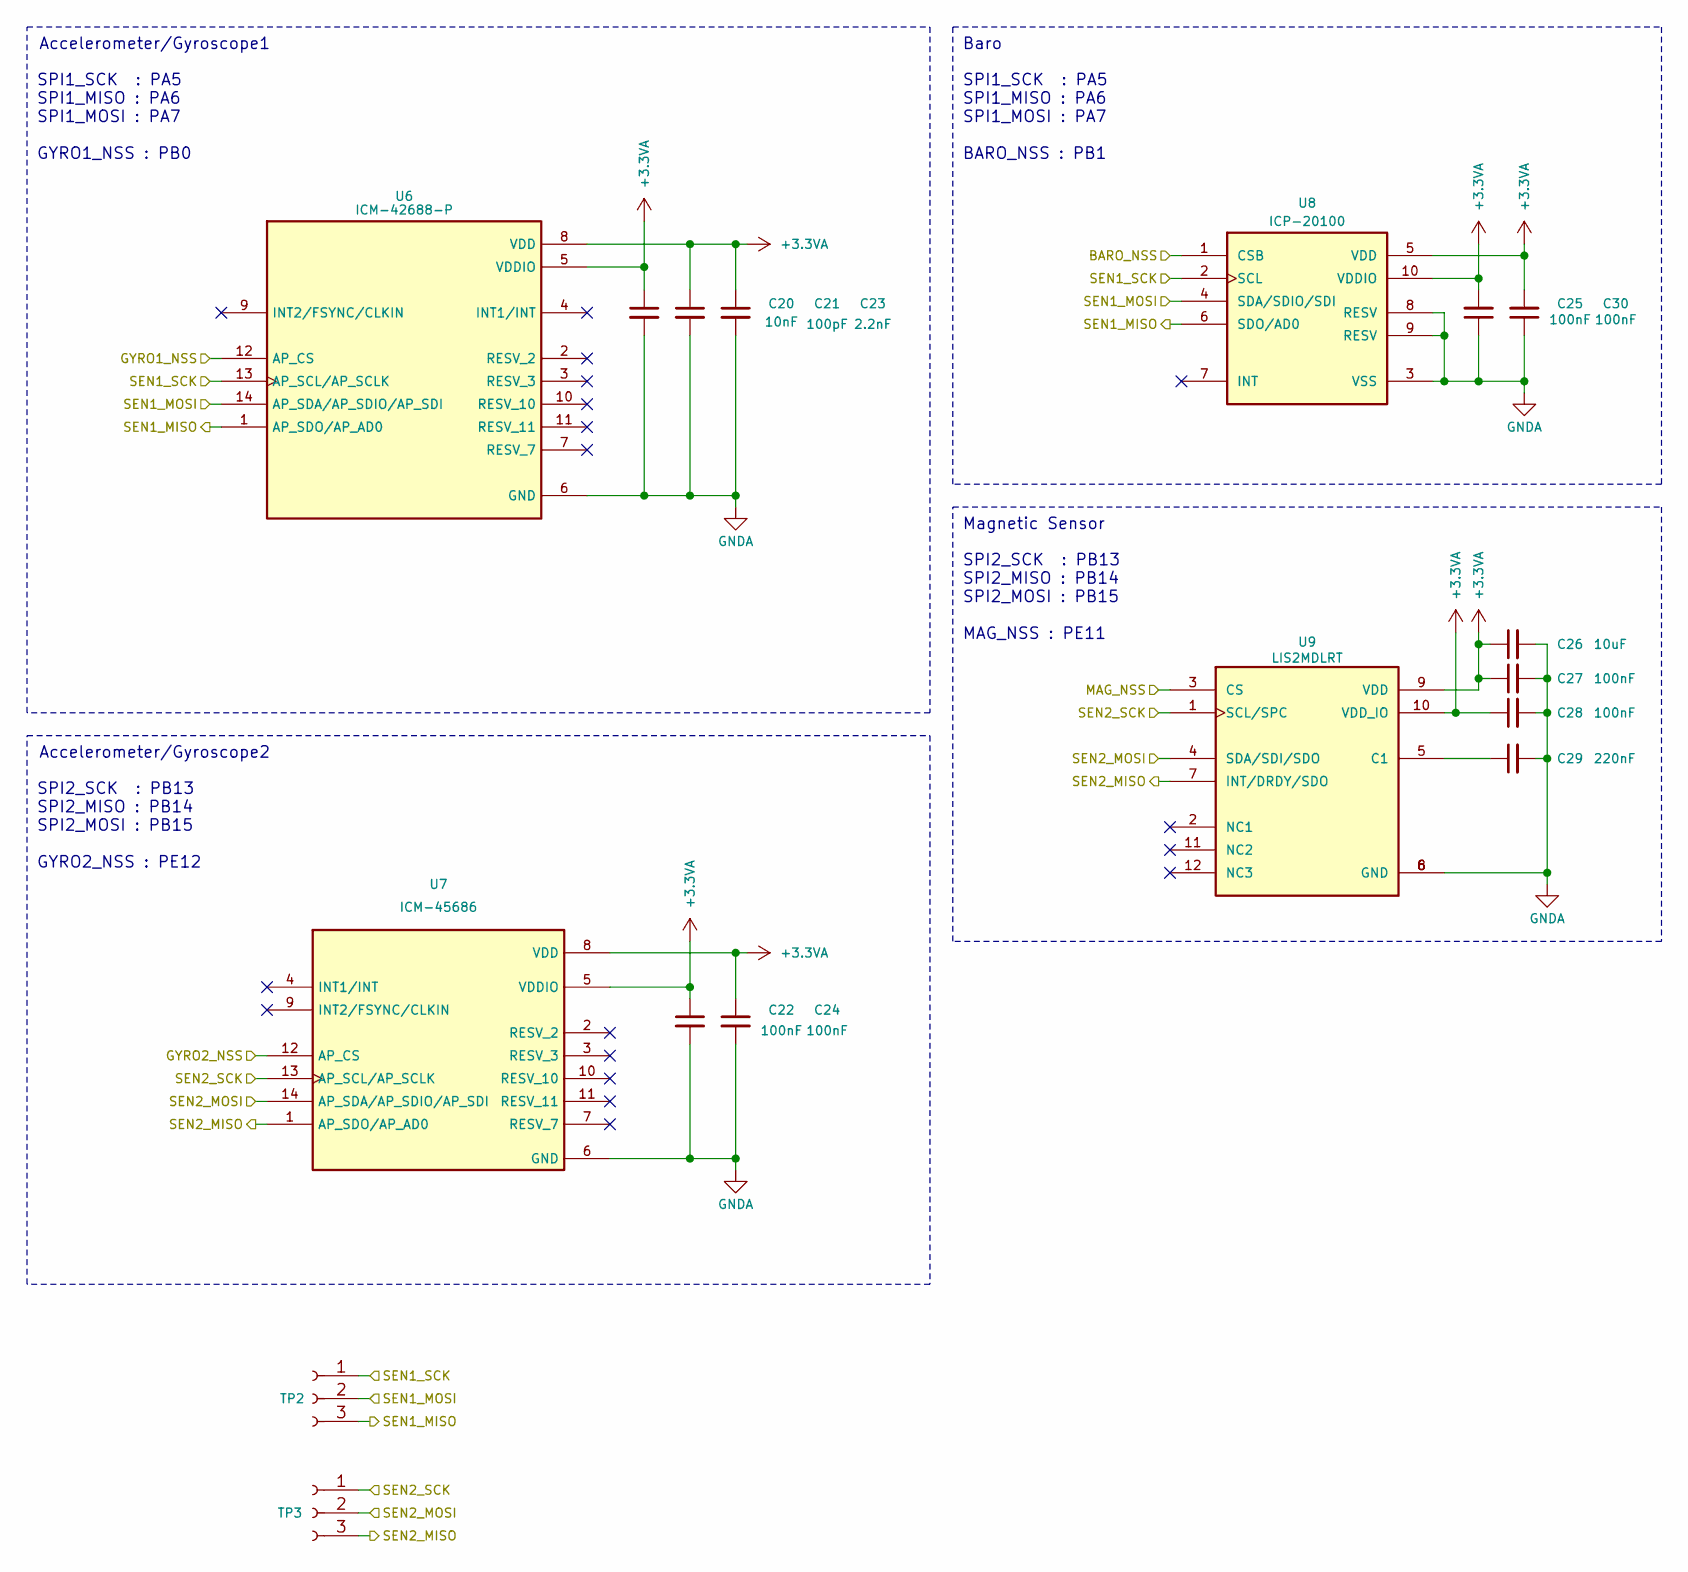
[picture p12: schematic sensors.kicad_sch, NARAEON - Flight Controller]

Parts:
C20: 10nF; C_0402_1005Metric; LCSC C15195
C21: 100pF; C_0402_1005Metric; LCSC C152819
C22, C24, C25, C27, C28, C30: 100nF; C_0402_1005Metric; LCSC C1525
C23: 2.2nF; C_0402_1005Metric; LCSC C84703
C26: 10uF; C_0402_1005Metric; LCSC C307415
C29: 220nF; C_0402_1005Metric; LCSC C16651
TP2, TP3: Test Pin; PinHeader_1x03_P1.27mm_Vertical; LCSC C24980
U6: ICM-42688-P; IIM42352_L; LCSC C1850418
U7: ICM-45686; LCSC C22459454
U8: ICP-20100; LCSC C5343527
U9: LIS2MDLRT; LIS2MDLTR; PARTREV Rev 5; LCSC C919695

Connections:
+3.3VA: C20.1, C21.1, C22.1, C23.1, C24.1, C25.2, C26.1, C27.1, C28.1, C30.2, U6.5 (VDDIO), U6.8 (VDD), U7.5 (VDDIO), U7.8 (VDD), U8.5 (VDD), U8.10 (VDDIO), U9.9 (VDD), U9.10 (VDD_IO); also elsewhere on the board
/BARO_NSS: U8.1 (CSB); also elsewhere on the board
/GYRO1_NSS: U6.12 (AP_CS); also elsewhere on the board
/GYRO2_NSS: U7.12 (AP_CS); also elsewhere on the board
/MAG_NSS: U9.3 (CS); also elsewhere on the board
/SEN1_MISO: TP2.3, U6.1 (AP_SDO/AP_AD0), U8.6 (SDO/AD0); also elsewhere on the board
/SEN1_MOSI: TP2.2, U6.14 (AP_SDA/AP_SDIO/AP_SDI), U8.4 (SDA/SDIO/SDI); also elsewhere on the board
/SEN1_SCK: TP2.1, U6.13 (AP_SCL/AP_SCLK), U8.2 (SCL); also elsewhere on the board
/SEN2_MISO: TP3.3, U7.1 (AP_SDO/AP_AD0), U9.7 (INT/DRDY/SDO); also elsewhere on the board
/SEN2_MOSI: TP3.2, U7.14 (AP_SDA/AP_SDIO/AP_SDI), U9.4 (SDA/SDI/SDO); also elsewhere on the board
/SEN2_SCK: TP3.1, U7.13 (AP_SCL/AP_SCLK), U9.1 (SCL/SPC); also elsewhere on the board
GNDA: C20.2, C21.2, C22.2, C23.2, C24.2, C25.1, C26.2, C27.2, C28.2, C29.2, C30.1, U6.6 (GND), U7.6 (GND), U8.3 (VSS), U8.8 (RESV), U8.9 (RESV), U9.6 (GND), U9.8 (GND); also elsewhere on the board
unnamed: C29.1, U9.5 (C1)

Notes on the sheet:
Magnetic Sensor
Accelerometer/Gyroscope1
SPI2_SCK : PB13 SPI2_MISO : PB14 SPI2_MOSI : PB15 GYRO2_NSS : PE12
SPI1_SCK : PA5 SPI1_MISO : PA6 SPI1_MOSI : PA7 GYRO1_NSS : PB0
SPI1_SCK : PA5 SPI1_MISO : PA6 SPI1_MOSI : PA7 BARO_NSS : PB1
Accelerometer/Gyroscope2
SPI2_SCK : PB13 SPI2_MISO : PB14 SPI2_MOSI : PB15 MAG_NSS : PE11
Baro

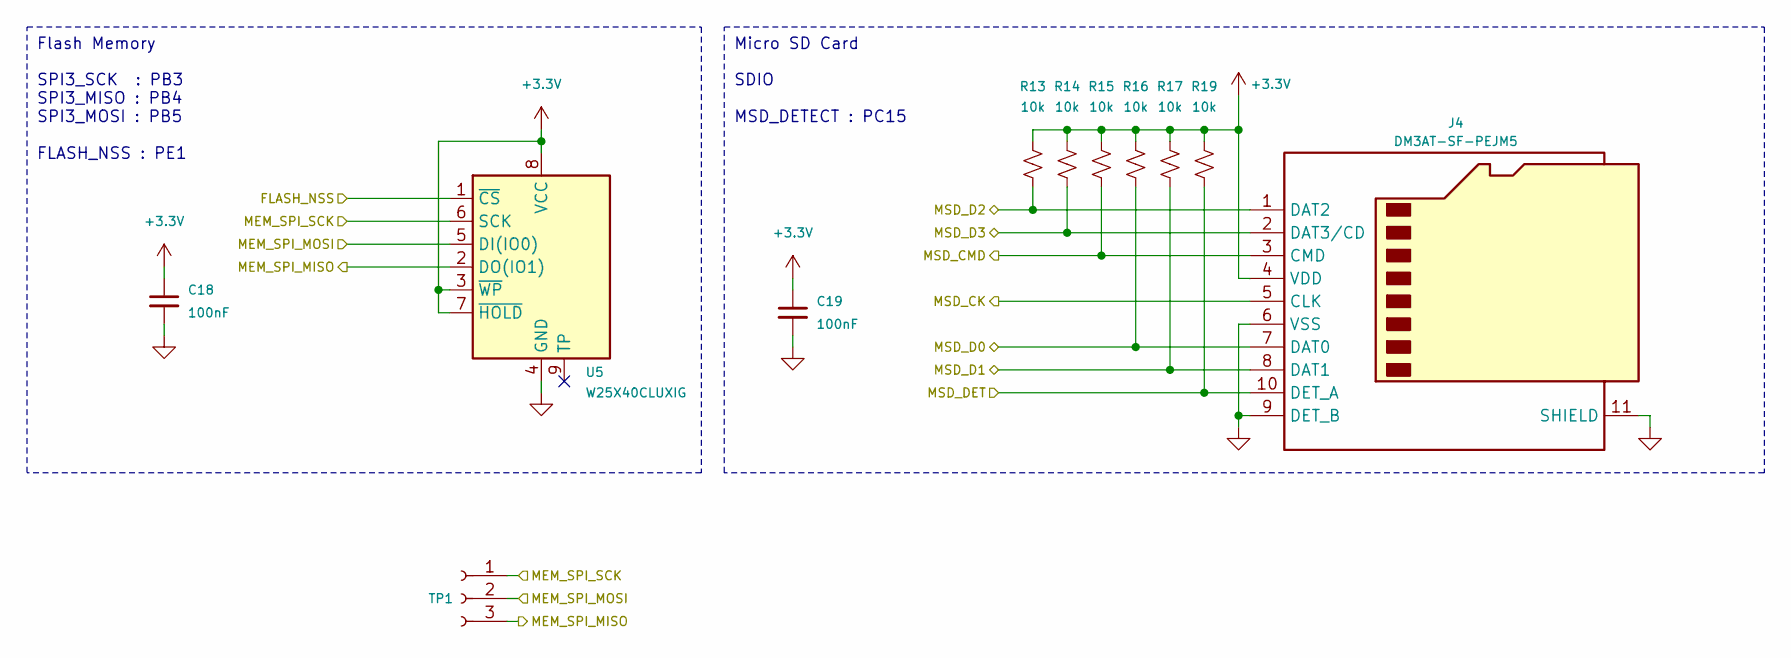
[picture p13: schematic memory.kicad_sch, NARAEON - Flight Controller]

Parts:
C18, C19: 100nF; C_0402_1005Metric; LCSC C1525
J4: DM3AT-SF-PEJM5; microSD_HC_Hirose_DM3AT-SF-PEJM5; LCSC C114218
R13, R14, R15, R16, R17, R19: 10k; R_0402_1005Metric; LCSC C25531
TP1: Test Pin; PinHeader_1x03_P1.27mm_Vertical; LCSC C24980
U5: W25X40CLUXIG; USON_LUXIG TR_WIN; LCSC C401661

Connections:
+3.3V: C18.1, C19.1, J4.4 (VDD), R13.1, R14.1, R15.1, R16.1, R17.1, R19.1, U5.3 (~WP), U5.7 (~HOLD), U5.8 (VCC); also elsewhere on the board
/FLASH_NSS: U5.1 (~CS); also elsewhere on the board
/MEM_MISO: TP1.3, U5.2 (DO(IO1)); also elsewhere on the board
/MEM_MOSI: TP1.2, U5.5 (DI(IO0)); also elsewhere on the board
/MEM_SCK: TP1.1, U5.6 (SCK); also elsewhere on the board
/MSD.CK: J4.5 (CLK); also elsewhere on the board
/MSD.D0: J4.7 (DAT0), R16.2; also elsewhere on the board
/MSD.D1: J4.8 (DAT1), R17.2; also elsewhere on the board
/MSD.D2: J4.1 (DAT2), R13.2; also elsewhere on the board
/MSD.D3: J4.2 (DAT3/CD), R14.2; also elsewhere on the board
/MSD_CMD: J4.3 (CMD), R15.2; also elsewhere on the board
/MSD_DETECT: J4.10 (DET_A), R19.2; also elsewhere on the board
GND: C18.2, C19.2, J4.6 (VSS), J4.9 (DET_B), J4.11 (SHIELD), U5.4 (GND); also elsewhere on the board

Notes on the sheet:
SDIO MSD_DETECT : PC15
SPI3_SCK : PB3 SPI3_MISO : PB4 SPI3_MOSI : PB5 FLASH_NSS : PE1
Flash Memory
Micro SD Card

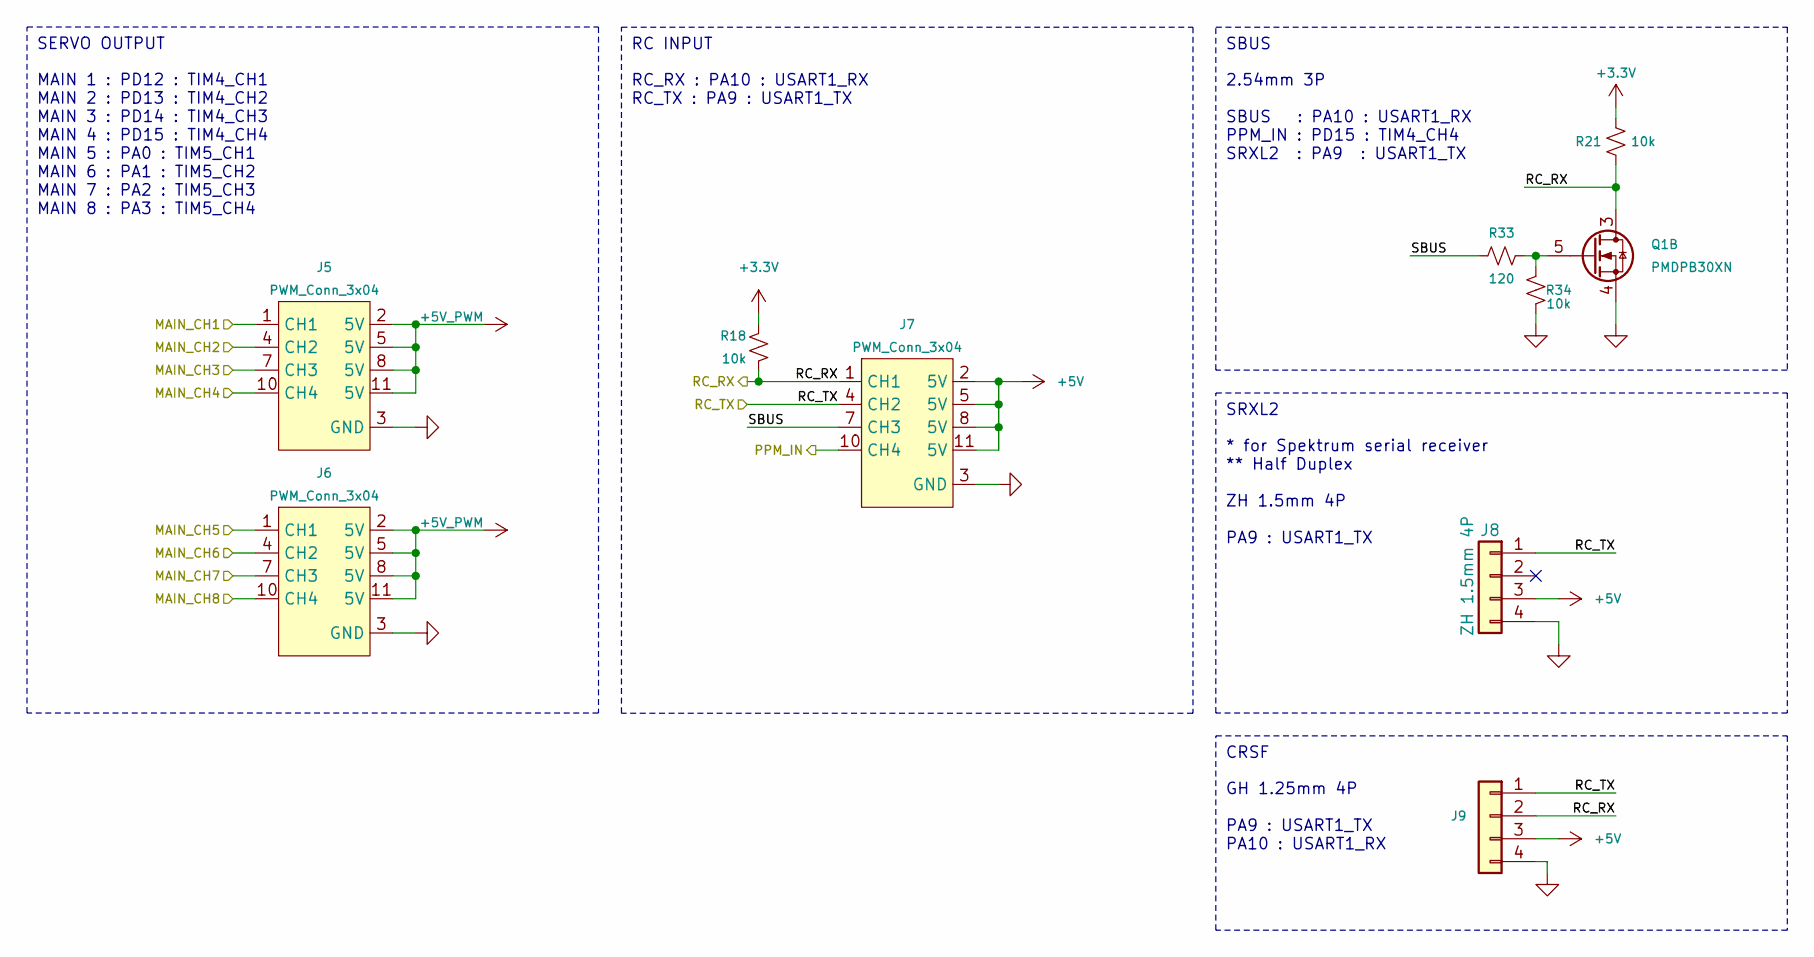
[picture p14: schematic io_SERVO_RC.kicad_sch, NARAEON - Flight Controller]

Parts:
J5, J6, J7: PWM_Conn_3x04; PWM_Conn_3x04_JLC; LCSC C3325573
J8: ZH 1.5mm 4P; JST_ZH_B4B-ZR-SM4-TF_1x04-1MP_P1.50mm_Vertical; LCSC C485354
J9: GH 1.25mm 4P; JST_GH_BM04B-GHS-TBT_1x04-1MP_P1.25mm_Vertical; LCSC C161692
Q1: PMDPB30XN; Nexperia_SOT1118; LCSC C478009
R18, R21, R34: 10k; R_0402_1005Metric; LCSC C25531
R33: 120; R_0402_1005Metric; LCSC C25079

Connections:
+3.3V: R18.1, R21.1; also elsewhere on the board
+5V: J7.2 (5V), J7.5 (5V), J7.8 (5V), J7.11 (5V), J8.3, J9.3; also elsewhere on the board
+5V_PWM: J5.2 (5V), J5.5 (5V), J5.8 (5V), J5.11 (5V), J6.2 (5V), J6.5 (5V), J6.8 (5V), J6.11 (5V); also elsewhere on the board
/MAIN1: J5.1 (CH1); also elsewhere on the board
/MAIN2: J5.4 (CH2); also elsewhere on the board
/MAIN3: J5.7 (CH3); also elsewhere on the board
/MAIN4: J5.10 (CH4); also elsewhere on the board
/MAIN5: J6.1 (CH1); also elsewhere on the board
/MAIN6: J6.4 (CH2); also elsewhere on the board
/MAIN7: J6.7 (CH3); also elsewhere on the board
/MAIN8: J6.10 (CH4); also elsewhere on the board
/PPM_IN: J7.10 (CH4); also elsewhere on the board
/RC_RX: J7.1 (CH1), J9.2, Q1.3 (D), Q1.8 (D), R18.2, R21.2; also elsewhere on the board
/RC_TX: J7.4 (CH2), J8.1, J9.1; also elsewhere on the board
/SERVO & RC/SBUS: J7.7 (CH3), R33.1
GND: J5.3 (GND), J5.6 (GND), J5.9 (GND), J5.12 (GND), J6.3 (GND), J6.6 (GND), J6.9 (GND), J6.12 (GND), J7.3 (GND), J7.6 (GND), J7.9 (GND), J7.12 (GND), J8.4, J9.4, Q1.4 (S), R34.2; also elsewhere on the board
unnamed: Q1.5 (G), R33.2, R34.1

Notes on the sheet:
SBUS
SRXL2
2.54mm 3P SBUS : PA10 : USART1_RX PPM_IN : PD15 : TIM4_CH4 SRXL2 : PA9 : USART1_TX
RC INPUT
RC_RX : PA10 : USART1_RX RC_TX : PA9 : USART1_TX
MAIN 1 : PD12 : TIM4_CH1 MAIN 2 : PD13 : TIM4_CH2 MAIN 3 : PD14 : TIM4_CH3 MAIN 4 : PD15 : TIM4_CH4 MAIN 5 : PA0 : TIM5_CH1 MAIN 6 : PA1 : TIM5_CH2 MAIN 7 : PA2 : TIM5_CH3 MAIN 8 : PA3 : TIM5_CH4
SERVO OUTPUT
CRSF
* for Spektrum serial receiver ** Half Duplex ZH 1.5mm 4P PA9 : USART1_TX
GH 1.25mm 4P PA9 : USART1_TX PA10 : USART1_RX

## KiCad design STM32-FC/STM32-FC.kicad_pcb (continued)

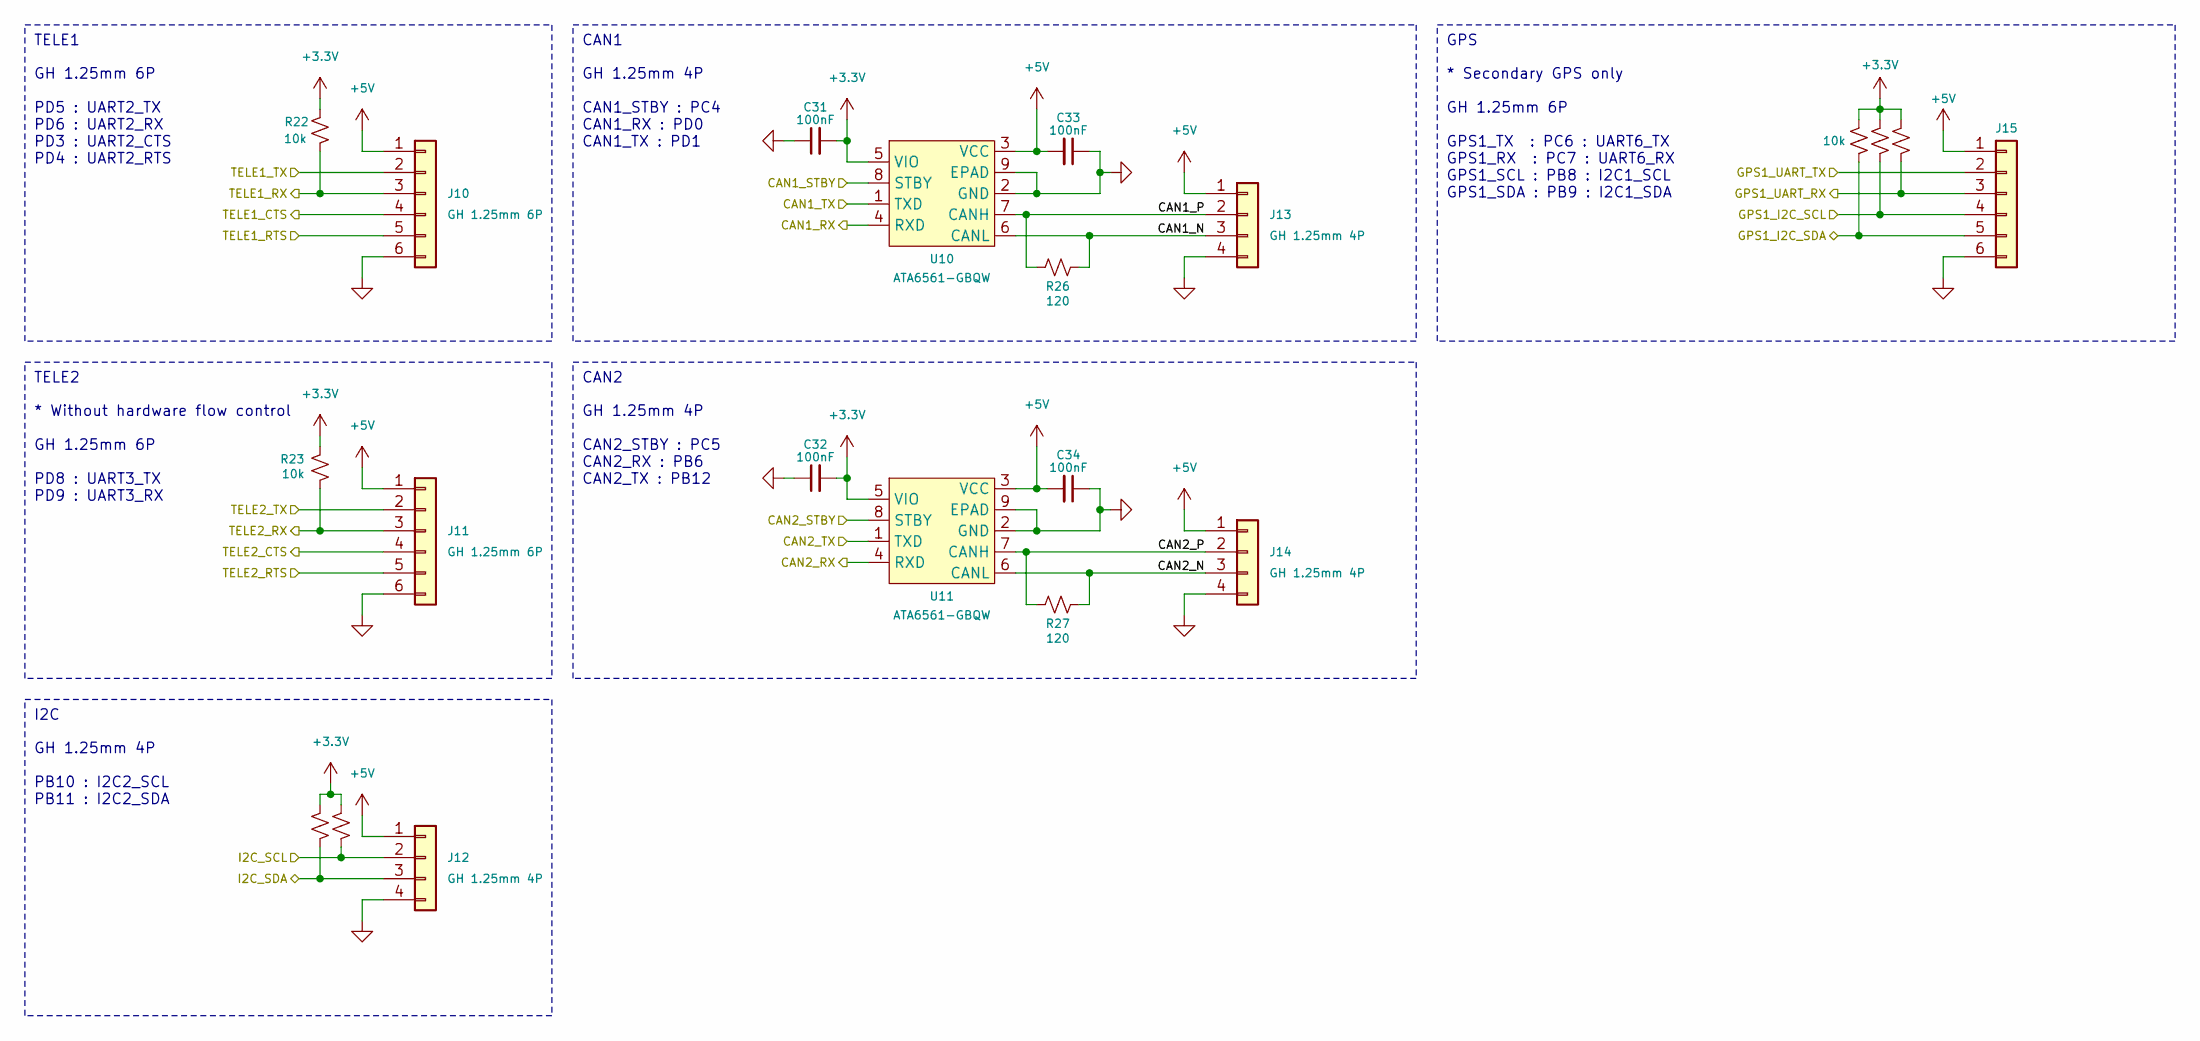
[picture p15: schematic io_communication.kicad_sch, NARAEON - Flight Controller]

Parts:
C31, C32, C33, C34: 100nF; C_0402_1005Metric; LCSC C1525
J10, J11, J15: GH 1.25mm 6P; JST_GH_BM06B-GHS-TBT_1x06-1MP_P1.25mm_Vertical; LCSC C189892
J12, J13, J14: GH 1.25mm 4P; JST_GH_BM04B-GHS-TBT_1x04-1MP_P1.25mm_Vertical; LCSC C161692
R22, R23, R24, R25, R28, R29, R30: 10k; R_0402_1005Metric; LCSC C25531
R26, R27: 120; R_0402_1005Metric; LCSC C25079
U10, U11: ATA6561-GBQW; VDFN8_3X3_MCH-L; LCSC C617297

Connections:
+3.3V: C31.2, C32.2, R22.1, R23.1, R24.1, R25.1, R28.1, R29.1, R30.1, U10.5 (VIO), U11.5 (VIO); also elsewhere on the board
+5V: C33.2, C34.2, J10.1, J11.1, J12.1, J13.1, J14.1, J15.1, U10.3 (VCC), U11.3 (VCC); also elsewhere on the board
/CAN1_RX: U10.4 (RXD); also elsewhere on the board
/CAN1_STBY: U10.8 (STBY); also elsewhere on the board
/CAN1_TX: U10.1 (TXD); also elsewhere on the board
/CAN2_RX: U11.4 (RXD); also elsewhere on the board
/CAN2_STBY: U11.8 (STBY); also elsewhere on the board
/CAN2_TX: U11.1 (TXD); also elsewhere on the board
/Communication/CAN1_N: J13.3, R26.2, U10.6 (CANL)
/Communication/CAN1_P: J13.2, R26.1, U10.7 (CANH)
/Communication/CAN2_N: J14.3, R27.2, U11.6 (CANL)
/Communication/CAN2_P: J14.2, R27.1, U11.7 (CANH)
/Communication/TELE2_CTS: J11.4
/Communication/TELE2_RTS: J11.5
/GPS1_RX: J15.3, R30.2; also elsewhere on the board
/GPS1_SCL: J15.4, R29.2; also elsewhere on the board
/GPS1_SDA: J15.5, R28.2; also elsewhere on the board
/GPS1_TX: J15.2; also elsewhere on the board
/I2C1_SCL: J12.2, R25.2; also elsewhere on the board
/I2C1_SDA: J12.3, R24.2; also elsewhere on the board
/UART2_CTS: J10.4; also elsewhere on the board
/UART2_RTS: J10.5; also elsewhere on the board
/UART2_RX: J10.3, R22.2; also elsewhere on the board
/UART2_TX: J10.2; also elsewhere on the board
/UART3_RX: J11.3, R23.2; also elsewhere on the board
/UART3_TX: J11.2; also elsewhere on the board
GND: C31.1, C32.1, C33.1, C34.1, J10.6, J11.6, J12.4, J13.4, J14.4, J15.6, U10.2 (GND), U10.9 (EPAD), U11.2 (GND), U11.9 (EPAD); also elsewhere on the board

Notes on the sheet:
CAN2
GH 1.25mm 4P CAN2_STBY : PC5 CAN2_RX : PB6 CAN2_TX : PB12
GH 1.25mm 4P CAN1_STBY : PC4 CAN1_RX : PD0 CAN1_TX : PD1
TELE1
CAN1
GH 1.25mm 6P PD5 : UART2_TX PD6 : UART2_RX PD3 : UART2_CTS PD4 : UART2_RTS
* Without hardware flow control GH 1.25mm 6P PD8 : UART3_TX PD9 : UART3_RX
I2C
GPS
GH 1.25mm 4P PB10 : I2C2_SCL PB11 : I2C2_SDA
TELE2
* Secondary GPS only GH 1.25mm 6P GPS1_TX : PC6 : UART6_TX GPS1_RX : PC7 : UART6_RX GPS1_SCL : PB8 : I2C1_SCL GPS1_SDA : PB9 : I2C1_SDA

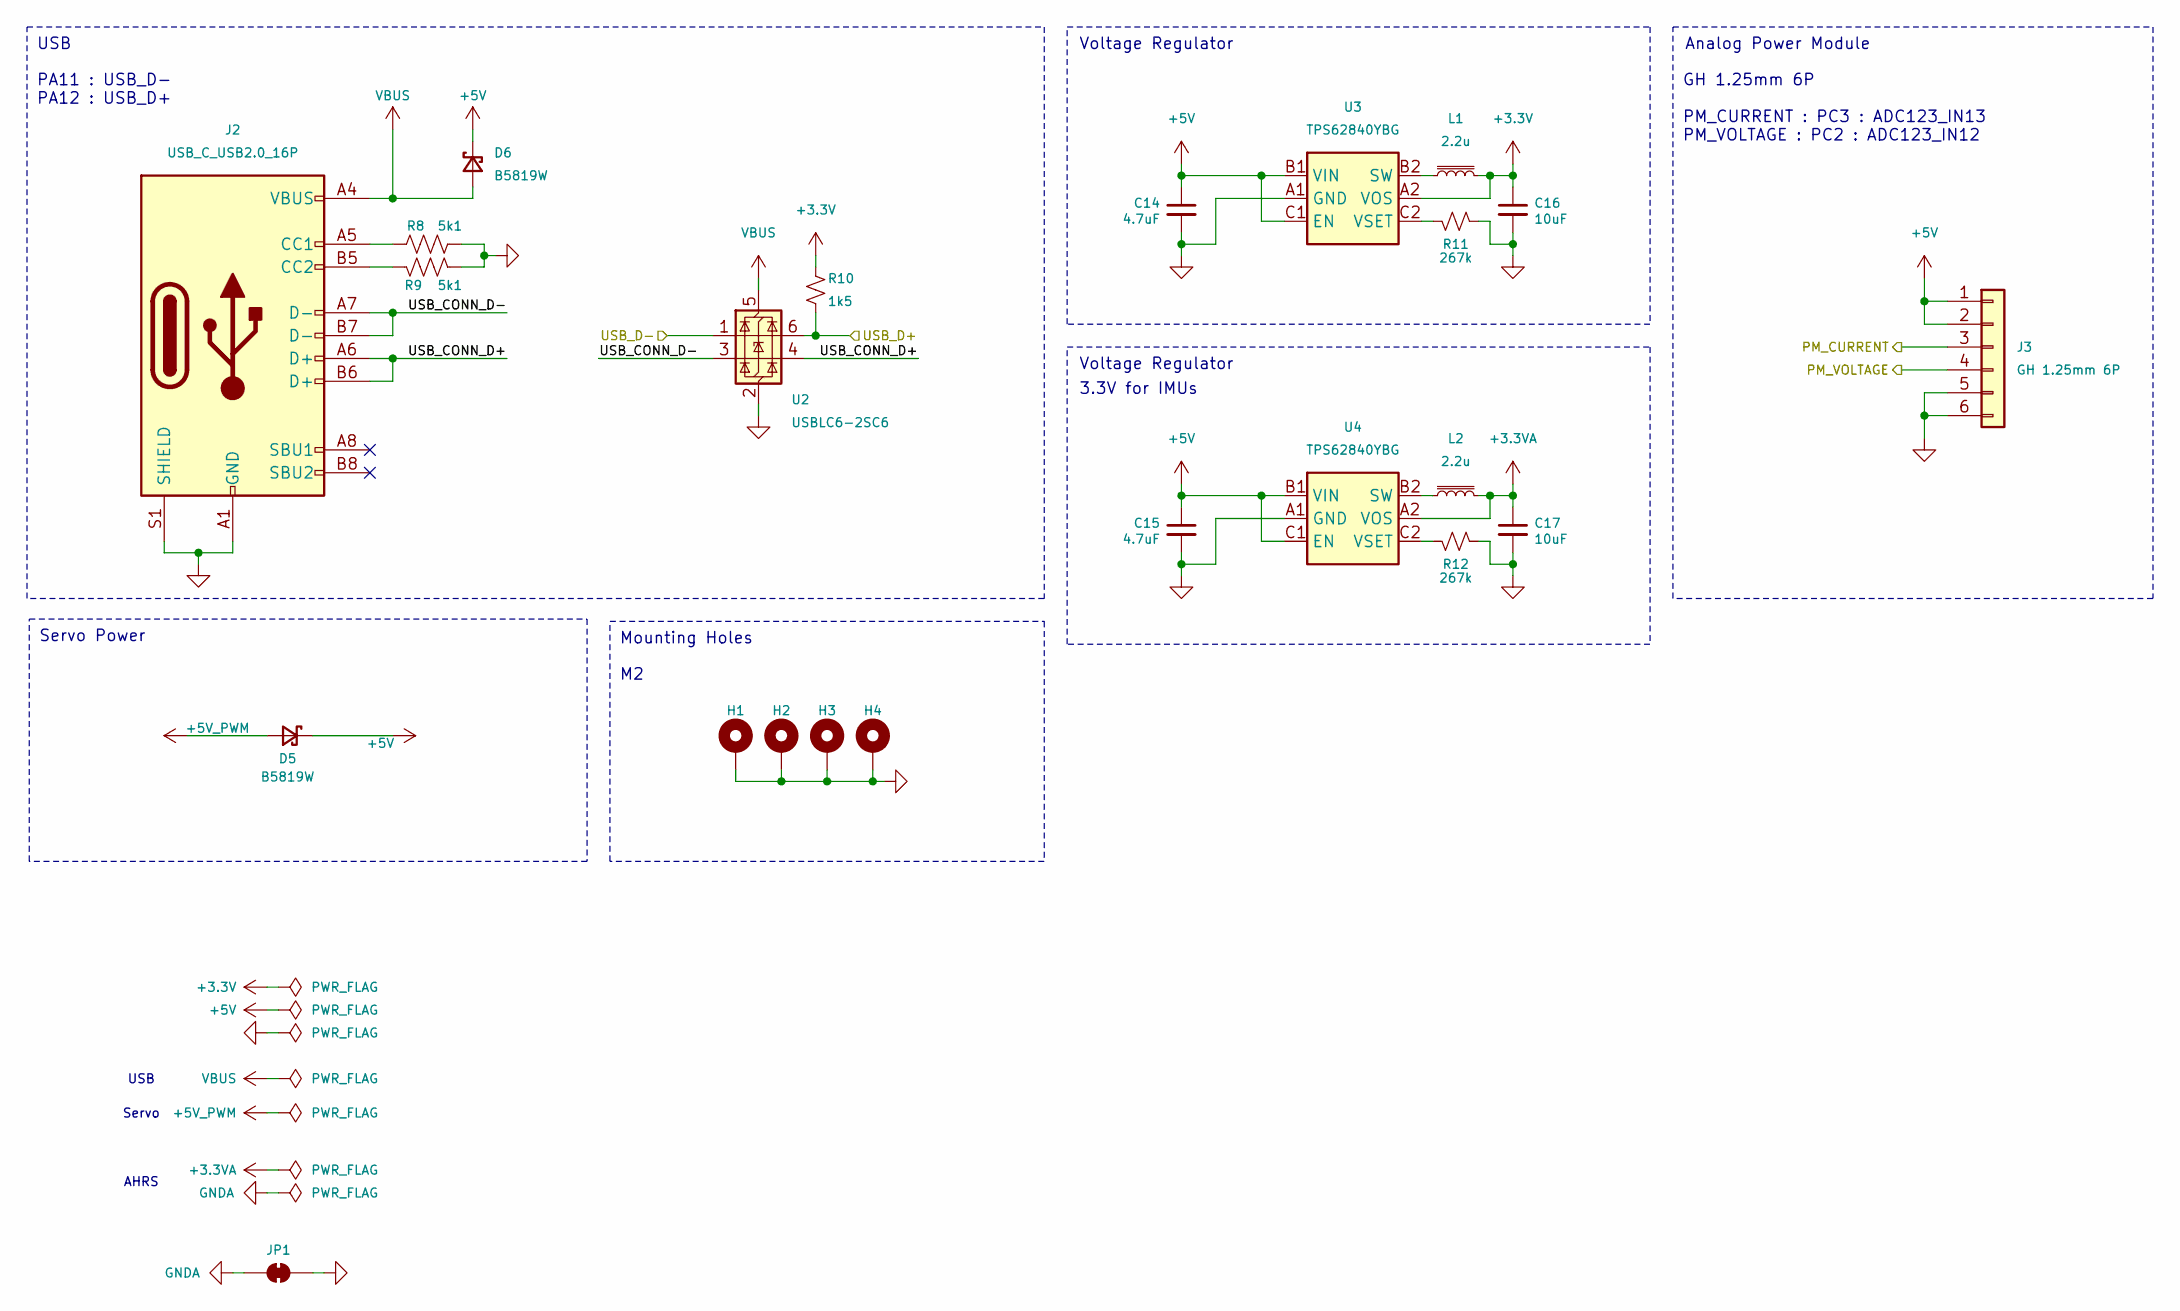
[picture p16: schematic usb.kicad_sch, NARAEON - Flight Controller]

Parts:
C14, C15: 4.7uF; C_0402_1005Metric; LCSC C307423
C16, C17: 10uF; C_0402_1005Metric; LCSC C307415
D5, D6: B5819W; D_SOD-323; LCSC C22624
H1, H2, H3, H4: MountingHole; MountingHole_2.2mm_M2_Pad
J2: USB_C_USB2.0_16P; USB_C_Receptacle_GCT_USB4105-xx-A_16P_TopMnt_Horizontal; LCSC C2765186
J3: GH 1.25mm 6P; JST_GH_BM06B-GHS-TBT_1x06-1MP_P1.25mm_Vertical; LCSC C189892
JP1: SolderJumper_2_Bridged; SolderJumper-2_P1.3mm_Bridged_RoundedPad1.0x1.5mm
L1, L2: 2.2u; VLS201610ET-2R2M; LCSC C114768
R8, R9: 5k1; R_0402_1005Metric; LCSC C25905
R10: 1k5; R_0402_1005Metric; LCSC C25867
R11, R12: 267k; R_0402_1005Metric; LCSC C2998050
U2: USBLC6-2SC6; SOT-23-6; LCSC C7519
U3, U4: TPS62840YBG; Texas_DSBGA-6_0.855x1.255mm_Layout2x3_P0.4mm_LevelC; LCSC C2071139

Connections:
+3.3V: C16.1, L1.2, R10.1, U3.A2 (VOS); also elsewhere on the board
+3.3VA: C17.1, L2.2, U4.A2 (VOS); also elsewhere on the board
+5V: C14.1, C15.1, D5.1 (K), D6.1 (K), J3.1, J3.2, U3.B1 (VIN), U3.C1 (EN), U4.B1 (VIN), U4.C1 (EN); also elsewhere on the board
+5V_PWM: D5.2 (A); also elsewhere on the board
/PM_CURRENT: J3.3; also elsewhere on the board
/PM_VOLTAGE: J3.4; also elsewhere on the board
/USB & POWER/USB_CONN_D+: J2.A6 (D+), J2.B6 (D+), U2.4 (I/O2)
/USB & POWER/USB_CONN_D-: J2.A7 (D-), J2.B7 (D-), U2.3 (I/O2)
/USB_D+: R10.2, U2.6 (I/O1); also elsewhere on the board
/USB_D-: U2.1 (I/O1); also elsewhere on the board
GND: C14.2, C15.2, C16.2, C17.2, H1.1, H2.1, H3.1, H4.1, J2.A1 (GND), J2.A12 (GND), J2.B1 (GND), J2.B12 (GND), J2.S1 (SHIELD), J3.5, J3.6, JP1.2 (B), R8.2, R9.2, R11.1, R12.1, U2.2 (GND), U3.A1 (GND), U4.A1 (GND); also elsewhere on the board
GNDA: JP1.1 (A); also elsewhere on the board
unnamed: J2.A5 (CC1), R8.1
unnamed: J2.B5 (CC2), R9.1
unnamed: L1.1, U3.B2 (SW)
unnamed: R11.2, U3.C2 (VSET)
unnamed: L2.1, U4.B2 (SW)
unnamed: R12.2, U4.C2 (VSET)
VBUS: D6.2 (A), J2.A4 (VBUS), J2.A9 (VBUS), J2.B4 (VBUS), J2.B9 (VBUS), U2.5 (VBUS)

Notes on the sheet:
Servo
Voltage Regulator
AHRS
3.3V for IMUs
Mounting Holes
Servo Power
Analog Power Module
GH 1.25mm 6P PM_CURRENT : PC3 : ADC123_IN13 PM_VOLTAGE : PC2 : ADC123_IN12
USB
PA11 : USB_D- PA12 : USB_D+

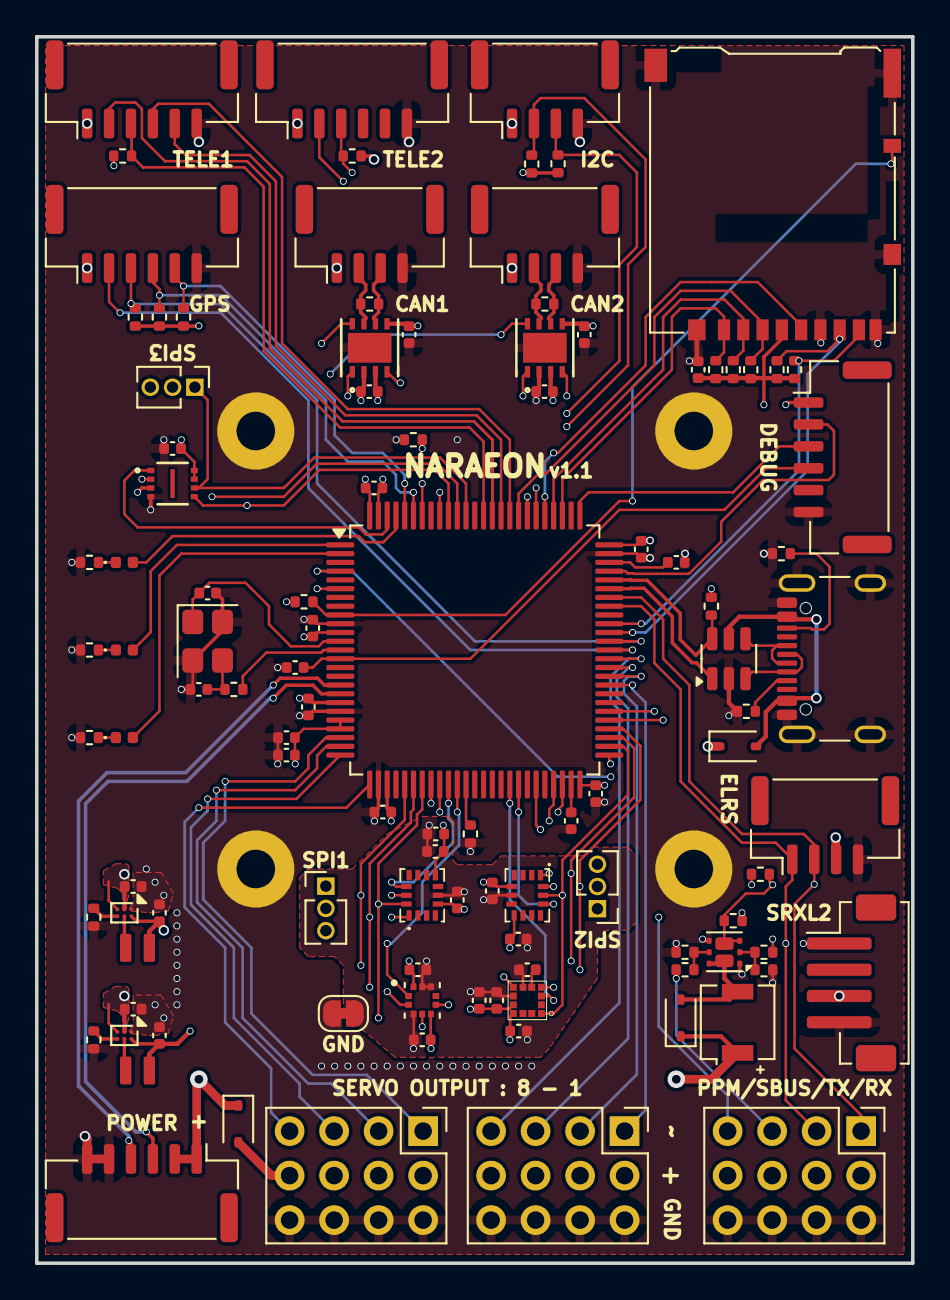
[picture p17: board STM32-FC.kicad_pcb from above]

Board: 4 copper layers, 50.0 x 70.0 mm, 111 parts (0 on the bottom side), 95 nets.

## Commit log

2025-08-05 fix : STM32 USB & VTX
    - USB DM/DP 결선 수정
    - VTX RX/TX 수정
    [STM32-FC.kicad_sch, usb.kicad_sch]
2025-08-09 init:footprint
    footprint 작업 시작
    [STM32-FC.kicad_pcb, STM32-FC.kicad_sch, STM32_io.kicad_sch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]
2025-08-12 fix:ATA6561 decap
    [AHRS.kicad_sch, io_communication.kicad_sch, memory.kicad_sch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]
2025-09-10 fix : BMM350 power 1.8V and add dc2dc converter for 1.8V
    [AHRS.kicad_sch, io_communication.kicad_sch, usb.kicad_sch]
2025-09-10 update : BOM and minor fix
    - remove : DC2DC for analog
    - change : JST SM conn. to BM
    - change : ELRS conn. to JST XH (instead of JST SM)
    - update : BOM List
    [AHRS.kicad_sch, STM32-FC.kicad_sch, STM32_io.kicad_sch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]
2025-09-10 change : RC size 0402 to 0201
    [AHRS.kicad_sch, STM32-FC.kicad_pcb, STM32-FC.kicad_sch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]
2025-09-10 remove : production files
    [STM32-FC_v2-B_Cu.gbr, STM32-FC_v2-B_Mask.gbr, STM32-FC_v2-B_Paste.gbr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]
2025-09-16 v1.0 rollback
    [3x1 Male Pin Header Angle.STEP, 3x1 Male Pin Header.STEP, 3x10 Male Pin Header Angle.STEP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]
2025-09-16 schematic update
    [STM32-FC.kicad_sch, io_GPS.kicad_sch, io_RC_INPUT.kicad_sch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]
2025-09-16 v1.0.1 update WIP
    repactor and USB C bug fix
    [STM32-FC.kicad_pcb, STM32-FC.kicad_sch, io_GPS.kicad_sch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]
2025-10-10 schematic update & lib update
    - ICM-45686
    - ICP-20100
    - Micro SD update SDIO instead of SPI
    - servo main output
    - DC2DC buck instead power regulator
    [STM32-FC.kicad_sch, io_RC_INPUT.kicad_sch, io_communication.kicad_sch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]
2025-10-10 add: servo power & comment
    - Servo power diode add
    - comment update
    [STM32-FC.kicad_sch, io_SERVO_RC.kicad_sch, io_communication.kicad_sch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]
2025-10-10 update : BJT to MOSFET
    [STM32-FC.kicad_pcb, STM32-FC.kicad_sch, io_SERVO_RC.kicad_sch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]
2025-10-10 WIP : pcb part layout &* BOM udpate
    [STM32-FC.kicad_pcb, STM32-FC.kicad_sch, bom.csv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]
2025-10-10 update : AHRS PCB layout & routing done
    [STM32-FC.kicad_pcb, STM32-FC.kicad_sch, io_SERVO_RC.kicad_sch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]
2025-10-10 PCB layout done
    [STM32-FC.kicad_pcb, STM32-FC.kicad_sch, bom.csv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]
2025-10-10 fix : readme & schematic minor fix
    - schematic comment fix
    [NARAEON.step, STM32-FC.kicad_pcb, STM32-FC.kicad_sch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]
2025-10-11 update : Development board
    [DevTool.kicad_pcb, DevTool.kicad_sch, STM32-FC.kicad_sch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]
